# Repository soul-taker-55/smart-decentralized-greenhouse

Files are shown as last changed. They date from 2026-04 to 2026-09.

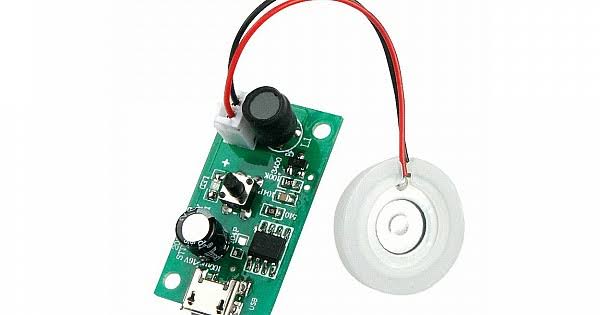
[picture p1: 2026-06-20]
Hardware Components/16) Ultrasonic Humidifier.jpg

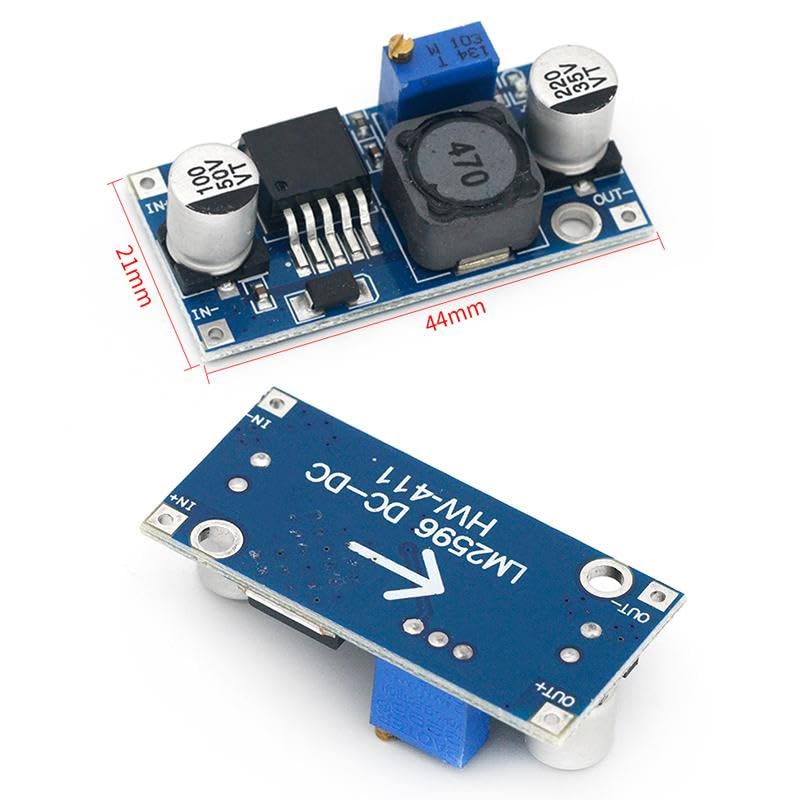
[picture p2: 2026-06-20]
Hardware Components/20) LM2596 HW-411 A.jpg

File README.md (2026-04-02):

# Smart Decentralized Greenhouse

A Secure and Decentralized IoT-Based Greenhouse Framework (SDIGF)

## Overview
This project presents an autonomous greenhouse system leveraging IoT devices, edge computing, and Zero Trust security principles.

## Key Concepts
- IoT
- Edge Computing
- Autonomous Control
- Zero Trust Architecture

## System Architecture

The system is designed as a decentralized IoT architecture consisting of:

- Device Layer (ESP32 sensors & actuators)
- Edge Layer (local decision-making)
- Communication Layer (MQTT over secure channels)
- Control Layer (automation logic)
- Monitoring Layer (dashboard & analytics)

## Team
- Ahmad Shaaban
- Dalaa Hag Mohammed
- Elias Zikra
- Maram Faisal Mohammed
- Mauricio Sayegh
- Omar Sawas

## Status
🚧 Under Development

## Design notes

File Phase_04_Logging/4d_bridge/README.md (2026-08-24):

# SDIGF Bridge — Phase 04d

Subscribes to the edge→server MQTT topics and writes what arrives into TimescaleDB.

Consumes the frozen contract at `Phase_04_Logging/4b_contracts/mqtt_contract_v3.md`.
Writes into the schema at `Phase_04_Logging/db/sdigf-db-schema-v2.sql`.

---

## What it is, and what it deliberately is not

The bridge is a **read-only observer of the edge**. It subscribes; it writes to Postgres;
it publishes nothing. It does not subscribe to `down/config` or `down/cmd`, and the
`sdigf-bridge` broker credential should not be granted publish rights on them.

Command publication belongs to the Phase 05a service layer. Keeping that line clean is
what makes it possible to say the logging tier has no path to an actuator — not as a
policy that could be relaxed, but as an absence of code.

The bridge is also **not in the control path**. If this process dies, the greenhouse keeps
running: the edge tier is autonomous by design and the only thing lost is the record. That
is the whole point of the tier split, and it is worth stating in the thesis in exactly
those terms.

---

## Topics

| Topic | QoS | Destination |
|---|---|---|
| `sdigf/v1/gh1/up/telemetry` | 0 | `telemetry` — 11 rows per message |
| `sdigf/v1/gh1/up/actuators` | 1 | `actuator_state` — 8 rows per message |
| `sdigf/v1/gh1/up/health` | 0 | `edge_events` — `HEALTH`, plus `REBOOT` when inferred |
| `sdigf/v1/gh1/up/ack` | 1 | `edge_events` — `ACK`, plus `CONFIG_APPLIED` when accepted |
| `sdigf/v1/gh1/status` | 1 | `edge_events` — `ONLINE` / `OFFLINE` |

Note that `status` sits at the root of the greenhouse tree, not under `up/`.

---

## Design decisions

### Time

`time` is **always the bridge's receipt time**. The device's own clock is preserved in
`device_ts`, and `ts_quality` records whether that clock was NTP-synced or boot-relative —
but neither drives the time axis.

The alternative, using the device clock when it is trustworthy and receipt time otherwise,
is more faithful to when a reading was taken. It was rejected because it produces a time
column whose meaning changes depending on a flag in another column. Any aggregate spanning
a reboot would silently mix two different notions of "when", and nothing in the query would
reveal it. One axis, one meaning, with the raw device value retained for anyone who wants
to reconstruct the other view.

All rows produced by a single message share one receipt timestamp, taken once.

### Deduplication

The contract requires uniqueness on `(greenhouse_id, seq, sensor_name)`. The schema's
unique index is on `(time, greenhouse_id, sensor_name, seq)` — TimescaleDB requires the
partitioning column in any unique index, so `time` cannot be left out.

**Those two are not the same guarantee.** Because `time` is receipt time, a QoS 1
redelivery arrives at a different instant and produces a different index key. The database
constraint would not catch it.

So the bridge checks explicitly before writing: has this `(greenhouse_id, seq)` already
been recorded within `DEDUP_WINDOW_MIN` minutes? QoS 1 redelivery happens within seconds of
a reconnect, so a 60-minute window is generous by orders of magnitude. The check is
DB-backed rather than in-memory, so it survives a bridge restart — which matters, because a
crash mid-processing is exactly when redelivery happens.

`ON CONFLICT DO NOTHING` remains on the insert as a second line of defence for the
exact-collision case.

> If this check ever shows up as slow, add:
> `CREATE INDEX ON telemetry (greenhouse_id, seq, time DESC);`
> At 30-second telemetry it is not close to mattering.

### Buffering and the bounded queue

MQTT delivery and database availability fail independently. Writes go into an in-memory
queue that drains in order, retrying with exponential backoff (1s → 30s cap).

The queue is **bounded** at `MAX_QUEUE_DEPTH`. When it fills, the oldest entry is discarded
and a counter increments. This is a deliberate trade: telemetry is QoS 0 and already
best-effort, so losing the oldest rows during a long outage is survivable, whereas an
unbounded queue turns a database outage into an OOM kill that loses everything *including*
the ability to recover. Drops are counted and logged rather than hidden.

Draining is strictly sequential. An `ONLINE` event followed by telemetry should land in
that order, and parallel writes would not guarantee it. Throughput is irrelevant at one
message per thirty seconds.

Constraint violations (Postgres error classes 22 and 23) are dropped rather than retried —
retrying a malformed row forever would wedge the queue behind one bad message.

### Persistent MQTT session

`clean: false` with a stable client ID. QoS 1 traffic — actuator state, acks, status — is
queued by the broker while the bridge restarts and delivered on reconnect. Telemetry is
QoS 0 and is not queued, which is the correct asymmetry: a gap in a 30-second sensor series
is recoverable from context, a missing `CONFIG_APPLIED` event is not.

### Validation before the write

The schema enforces the null rule with a CHECK constraint, so an invalid payload would be
rejected regardless. But it would be rejected as an opaque constraint violation at write
time, long after the context that would explain it is gone. Validating in the handler means
the log line names the sensor and the reason:

```
[error] [telemetry] rejected message: temp_in: q='fail' must carry val=null, got 0
```

A **missing** sensor is not treated as fatal — it is recorded as `init`, which is precisely
what "never successfully read" means, and the other ten readings are still evidence. An
**unrecognised** sensor is logged and ignored, so a firmware version that adds a sensor does
not stop the bridge writing the ones it understands.

### Reboot detection

The ESP32 cannot announce a reboot it has not yet booted from. The only available signal is
uptime going backwards between two health messages. When that happens the bridge writes a
distinct `REBOOT` row.

This matters because `boot_reason = brownout` is the documented signature of a stalled
canopy servo or an ESP32-CAM inrush on the shared 5 V rail, and `cfg_src = nvs` on the same
row is direct evidence of edge autonomy — the device restarted with no broker and resumed
from last-known-good config. Both would otherwise be buried inside a routine `HEALTH` row
among hundreds.

### Known omissions

`canopy.target` and `canopy.moving` are **not stored** — the schema has no column for them.
Both are transient: `moving` is true for under a second per adjustment, and `target` equals
`pos` except during that window. Neither answers a Phase 04 conflict question. Recorded here
so the omission is a decision on the record rather than something to rediscover later.

`vent` is stamped onto every row of a message rather than stored once. This is
denormalisation, and it is intentional: `vent` is derivable from the fan states, but the
contract publishes it because it is the value the control policy actually acted on. A
conflict query asking *what stage were we at when the humidifier was suppressed* should not
have to re-derive the policy's reasoning from its own outputs.

---

## Deployment

Separate Dokploy stack, same pattern as `sdigf-mock`.

Environment variables — set in Dokploy's environment tab, never committed:

```
MQTT_HOST=<broker host on dokploy-network>
MQTT_PORT=1883
MQTT_USER=sdigf-bridge
MQTT_PASS=<secret>

PG_HOST=<db service name on dokploy-network>
PG_PORT=5432
PG_USER=postgres
PG_PASS=<secret>
PG_DB=sdigf_db

GH_ID=gh1
LOG_LEVEL=info
MAX_QUEUE_DEPTH=5000
DEDUP_WINDOW_MIN=60
```

Use the **`sdigf-bridge`** credential, not `sdigf-edge` or `sdigf-admin`.

The bridge verifies the database is reachable and the schema is present *before* connecting
to the broker. Connecting to MQTT first would mean buffering messages it may have no ability
to store, and a wrong password would surface minutes later as a queue-depth warning rather
than immediately as what it is.

---

## Verifying it works

```sql
-- Is anything arriving?
SELECT count(*), max(time) FROM telemetry;

-- All eleven sensors, most recent message
SELECT sensor_name, value, unit, quality_flag
FROM telemetry
WHERE seq = (SELECT max(seq) FROM telemetry)
ORDER BY sensor_name;

-- Any duplicates? Should return zero rows.
SELECT greenhouse_id, seq, sensor_name, count(*)
FROM telemetry
GROUP BY 1,2,3 HAVING count(*) > 1;

-- Sensor health over the last day
SELECT sensor_name, quality_flag, count(*)
FROM telemetry
WHERE time > now() - interval '1 day'
GROUP BY 1,2 ORDER BY 1,2;

-- Connection and config history
SELECT time, event_type, boot_reason, cfg_src, cfg_ver
FROM edge_events
WHERE event_type IN ('ONLINE','OFFLINE','REBOOT','CONFIG_APPLIED')
ORDER BY time DESC LIMIT 20;
```

The bridge also logs a status line every five minutes:

```
[info] [bridge] status {"written":412,"duplicatesSkipped":3,"rejected":0,"dropped":0,"queueDepth":0}
```

---

## Testing performed

Verified against a live Mosquitto broker and a Postgres instance loaded with the real
schema, driven by the actual `4c_tool/mock-edge` simulator:

- 24 parser unit tests covering contract edge cases — null rule both directions, sentinel
  rejection, invalid quality flags, missing and unexpected sensors, out-of-range `vent` and
  `canopy.pos`, non-boolean `on`, invalid `src`, `ovr_s` present only when manual
- End-to-end: mock → broker → bridge → Postgres, 11 rows per telemetry message, 8 per
  actuator message, correct units and quality flags
- Retained `status` and `actuators` messages consumed on subscribe
- Duplicate suppression confirmed on a republished retained actuator message
- `ACK` accepted → `ACK` + `CONFIG_APPLIED` rows; rejected → `ACK` row and a warning
- Reboot inference from decreasing uptime, with `boot_reason=brownout` and `cfg_src=nvs`
  landing correctly
- Malformed JSON discarded without crashing
- Database stopped mid-run: 5 messages buffered, backoff 1s→2s→4s, all 55 rows recovered on
  restart, zero dropped

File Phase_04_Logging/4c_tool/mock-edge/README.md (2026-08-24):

# SDIGF Mock Edge Node

A stand-in for the ESP32. Publishes on the frozen MQTT contract
(`Contracts/mqtt_contract_v1.md`) so the entire server tier can be built,
tested, and demonstrated before firmware exists.

This is **not throwaway code**. It becomes the permanent test harness, the
regression suite, and the rehearsal target for the committee demonstration.
The control loop written here (Stage 2) is the reference implementation later
ported to firmware.

---

## Build stages

| Stage | Scope | Status |
|---|---|---|
| **1** | Connect, last will, telemetry, health, static actuator state | ✅ this release |
| 2 | Physics + control loop — actuators respond causally | planned |
| 3 | Config handling, safety envelope, acks | planned |
| 4 | Failure simulation, time acceleration, forced conditions | planned |

### What Stage 1 does

- Connects to EMQX with credentials and a **last will** on `status`
- Publishes `up/telemetry` every 10 s with all 11 readings, each carrying a
  quality flag, matching the contract exactly
- Publishes `up/health` every 60 s
- Publishes `up/actuators` once at connect (everything off — Stage 2 makes it real)
- Publishes retained `online` / `offline` on `status`
- Simulates ambient drift with bounded mean-reverting random walks, so charts
  and downsampling behave as they will in production

### What Stage 1 does *not* do

No physics linking actuators to conditions. No control loop. It does not
subscribe to `down/config` or `down/cmd`, and never sends an `up/ack`.
Soil moisture falls slowly and never recovers, because there is no pump yet.

---

## Deployment

Deployed as its **own Dokploy compose stack**, separate from `sdigf-server`, so
it can be stopped and started without touching the broker or database.

### 1. Create the stack

Dokploy → project `sdigf` → **Docker Compose** → Create

| Field | Value |
|---|---|
| Name | `sdigf-mock` |
| Provider | GitHub |
| Repository | `smart-decentralized-greenhouse` |
| Branch | `main` |
| Compose Path | `Tools/mock-edge/docker-compose.yml` |
| Watch Paths | `Tools/mock-edge/**` |

### 2. Environment variables

| Name | Value |
|---|---|
| `MQTT_HOST` | `sdigf-emqx` — the container name on `dokploy-network`, not the public domain |
| `MQTT_PORT` | `1883` |
| `MQTT_USER` | `sdigf-edge` |
| `MQTT_PASS` | the password set for `sdigf-edge` in EMQX |

Using the internal container name keeps mock traffic off the public interface
entirely. If the container name differs, take it from `docker ps`.

### 3. Deploy

Dokploy builds the image and starts the container. Logs should show:

```
[mqtt] connected to sdigf-emqx:1883 as sdigf-mock-edge
[mock] publishing telemetry every 10s, health every 60s
```

---

## Verification

**In MQTTX**, connect as `sdigf-admin` and subscribe to `sdigf/v1/gh1/#`.

| Check | Expected |
|---|---|
| Telemetry arrives | a message every 10 s on `up/telemetry` |
| Values drift | consecutive readings differ slightly, not identical |
| `seq` increments | 1, 2, 3 … with no gaps |
| Health arrives | every 60 s on `up/health`, retained |
| Status is online | `up/status` shows `{"state":"online"}` with the **Retained** badge |

**In the EMQX dashboard**, Clients should list `sdigf-mock-edge` as connected,
and Messages In Rate should be non-zero.

**Last-will test.** Stop the stack in Dokploy — that is a graceful stop, so the
mock publishes `offline` itself. To test the *will* specifically (ungraceful
disconnect), kill the container:

```bash
docker kill <mock-container-name>
```

The broker then publishes the retained `offline` message on its behalf. Stage 4
adds a cleaner way to trigger this for demo purposes.

---

## Configuration

All via environment variables; nothing is hardcoded.

| Variable | Default | Meaning |
|---|---|---|
| `MQTT_HOST` | *required* | Broker hostname |
| `MQTT_PORT` | `1883` | Broker port |
| `MQTT_USER` | *required* | Broker username |
| `MQTT_PASS` | *required* | Broker password |
| `MQTT_CLIENT_ID` | `sdigf-mock-edge` | Fixed, matching the real ESP32 pattern |
| `GH_ID` | `gh1` | Greenhouse slot in the topic tree |
| `FW_VERSION` | `mock-0.1.0` | Reported in `up/health` |
| `TELEMETRY_INTERVAL_S` | `10` | Telemetry publish interval |
| `HEALTH_INTERVAL_S` | `60` | Health publish interval |

---

## Swapping to the real ESP32

The intended endpoint is that swapping in real hardware is a **connection
change and nothing else**. Same topics, same payloads, same client ID pattern.
Stop this stack, power on the ESP32, and the server tier should not notice.

Note the one honest difference: this mock reports `tsq: "ntp"` because it runs
on a server with a real clock. The ESP32 reports `tsq: "boot"` until NTP syncs,
and the bridge must handle that case — see contract §2.

---

## Files

```
Tools/mock-edge/
├── docker-compose.yml     Dokploy stack definition
├── Dockerfile             node:20-alpine, runs as non-root
├── package.json
├── README.md
└── src/
    ├── config.js          Environment config and topic construction
    ├── environment.js     Simulated conditions (Stage 2 adds actuator physics)
    └── index.js           MQTT connection and publish loops
```

Topics are constructed in exactly one place (`config.js`) so a typo cannot
diverge between publishers.

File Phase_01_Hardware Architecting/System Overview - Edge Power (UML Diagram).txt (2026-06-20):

@startuml
skinparam rectangleBorderColor #555
rectangle "220-230 V AC mains" as mains
rectangle "S-25-5 PSU" as psu
rectangle "5 V rail" as r5 #ffe8e0
rectangle "LM2596 buck" as buck
rectangle "3.3 V rail" as r33 #e0ecff
rectangle "Grow light 220 V\n(relay CH7, mains-isolated)" as grow
rectangle "ESP32 5V pin\nrelay coils (JD-VCC)\nLCD, MQ135 heater\nMG996R servo (V+)\nDC loads via relay contacts" as loads5 #ffe8e0
rectangle "BMP280 x2, DHT11 x2\nLDR x2, soil, water\nencoder, relay logic (VCC)\nlevel-converter LV" as loads33 #e0ecff

mains --> psu
psu --> r5
r5 --> buck
buck --> r33
mains --> grow
r5 --> loads5
r33 --> loads33
@enduml

@startuml
left to right direction
skinparam rectangleBorderColor #555
rectangle "220-230 V AC mains" as mains
rectangle "S-25-5 PSU" as psu
rectangle "5 V rail" as r5 #ffe8e0
rectangle "LM2596 buck" as buck
rectangle "3.3 V rail" as r33 #e0ecff
rectangle "Grow light 220 V\n(relay CH7, mains-isolated)" as grow
rectangle "ESP32 5V pin\nrelay coils (JD-VCC)\nLCD, MQ135 heater\nMG996R servo (V+)\nDC loads via relay contacts" as loads5 #ffe8e0
rectangle "BMP280 x2, DHT11 x2\nLDR x2, soil, water\nencoder, relay logic (VCC)\nlevel-converter LV" as loads33 #e0ecff

mains --> psu
psu --> r5
r5 --> buck
buck --> r33
mains --> grow
r5 --> loads5
r33 --> loads33
@enduml

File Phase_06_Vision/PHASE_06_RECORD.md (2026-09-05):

# PHASE 06 RECORD — Vision Node (ESP32-CAM)

**Status:** device firmware live, server tier deployed to `greenhouse.progrex.tech`,
scheduled upload path verified end to end on real hardware. One path — the
manual snapshot request — is **built but not yet confirmed working**.
**Commits:** `e10f429` … `3a696ea` (20 commits, 3–4 September 2026). Base: `77988d4`.
**Hardware:** AI-Thinker ESP32-CAM, MAC `B4:BF:E9:34:4C:18`, 4 MB flash, PSRAM present.

This record states what was decided, what was found, what was wrong, and what
was observed — in that order.

---

## 1. What Phase 06 contributes — stated narrowly

A camera that photographs the enclosure on a schedule, uploads over HTTPS, and
presents its history in the dashboard.

It contributes **nothing to control**. The vision node cannot move an actuator,
cannot approve a config, and holds no role in the RBAC matrix. If it fails
entirely, the greenhouse is unaffected. That isolation is the point, and it is
enforced structurally rather than by convention: `camera_images` has no
relationship to `config_profiles` or `commands`, and the device's credential
(`device-auth.js`) is checked by a module that imports nothing from `auth.js`
and exports nothing to it.

What it does not yet contribute: any analysis. Green coverage, leaf area and
growth measurement are **not built**. This phase produces the dataset those
would need; it does not consume it.

---

## 2. The hardware is not what it was sold as

**The board is labelled ESP32-CAM with an OV2640. The sensor is not an OV2640.**

Sensor PID reads `0x2145` — OV7670-class. The distinguishing property, and the
one that mattered: **it has no hardware JPEG encoder.**

This was discovered the hard way. `esp_camera_init()` failed with `0x106` and
the driver's own message was misleading:

```
E (1958) camera: JPEG format is not supported on this sensor
[CAM] init FAILED 0x106
```

Read carelessly, "not supported on this sensor" suggests a misidentified or
faulty sensor. It means exactly what it says: the sensor was identified
correctly and cannot produce JPEG. The fix was a format change
(`PIXFORMAT_JPEG` → `PIXFORMAT_RGB565`), not a hardware change.

The diagnostic that settled it was a controlled comparison, not reasoning:

| camera connected | camera physically removed |
|---|---|
| `JPEG format is not supported on this sensor` | `Detected camera not supported` |

Two different messages means the driver was reading the sensor successfully in
one case and not at all in the other. That distinction is what ruled out a
connection fault.

### The consequence, measured

Raw RGB565 at QVGA is 153,600 bytes per frame — too large to upload at any
useful interval. Software encoding via `frame2jpg()` was chosen over buying a
genuine OV2640, because a replacement part was not available.

Measured on the device:

```
[JPG] #1  raw 153600 B -> jpg 7160 B  (21.5x)  104 ms  heap 173216
[JPG] #2  raw 153600 B -> jpg 7338 B  (20.9x)  103 ms  heap 172952
[JPG] #3  raw 153600 B -> jpg 7299 B  (21.0x)  101 ms  heap 172952
[JPG] #4  raw 153600 B -> jpg 7250 B  (21.2x)  100 ms  heap 172952
```

**~7 KB per frame, ~100 ms encode, heap flat across frames.** At one frame per
day that is roughly 2.5 MB a year.

This is worth stating plainly for the thesis: the workaround is not a
compromise in outcome. The bandwidth objection to a JPEG-less sensor
disappeared once the numbers were measured. It cost ~100 ms of CPU on a device
with no latency requirement. **The case for replacing the sensor is weaker
after measurement than it was before it** — which is the opposite of what was
assumed when the mismatch was found.

---

## 3. Two hardware faults that were not code faults

Both cost significant time and both were diagnosed wrongly at first. Recording
them because the wrong diagnoses are as instructive as the right ones.

### 3.1 The flash failure was a 5 V/3.3 V miswiring

Symptom: `esptool` connected, identified the chip, wrote the bootloader, then
failed verification with the **same MD5 every time**:

```
Input MD5: 42863d8b59e70f04bf1f3b0d5aae512e
Flash MD5: 7122cb1ef38a66d8813a9f9913af4682
```

Four theories were proposed and all four were wrong: serial noise, baud rate,
flash write-protection, and a counterfeit flash die. Each was ruled out by
evidence — the status register read `0x0000` (no protection), the failure
persisted at 115200 as well as 460800 (not baud), and the identical MD5 across
attempts ruled out random noise.

The actual cause: **the module was wired to 3.3 V instead of 5 V.** Enough to
boot, enough to talk over UART, not enough for the flash die to complete
writes.

The diagnostic signal that should have been weighted higher, and was noticed
but dropped:

```
Erasing flash memory (this may take a while)...
Flash memory erased successfully in 0.0 seconds.
```

A real erase of 4 MB does not complete in 0.0 seconds. That line was visible
from the first failed attempt.

### 3.2 The brownout was FTDI-supplied power

After flashing worked, the first upload succeeded and the second reset the
board:

```
[UP ] OK  status 201  1841 ms  (ok=1 fail=0)
[JPG] #2  7798 B  heap 157472
E BOD: Brownout detector was triggered
```

The upload path draws more current than anything tested before it: capture,
software JPEG encode, TLS handshake and WiFi transmit all inside a few hundred
milliseconds. The FTDI adapter's 5 V pin could not supply the spike.

Moving the CAM's 5 V and GND to the S-25-5 PSU rail resolved it. Uploads have
run without a brownout since.

**This is not a design flaw discovered — it is the documented power constraint
in the Phase 01 wiring doc arriving on schedule.** The CAM's own solid 5 V feed
was specified before any of this was built. The bench setup violated it.

---

## 4. Design decisions

### 4.1 Polling, not push — forced by the network, not chosen

The server cannot open a connection to the camera. The device sits on its own
WiFi network behind NAT with no inbound port. Every exchange is therefore the
camera asking the server.

This is the same shape as the retained-config pattern in Phase 04/05a — state
the device discovers rather than state delivered to it — arrived at
independently, for the same underlying reason.

It has a visible consequence the UI must not hide: **pressing "Request
snapshot" cannot produce an image immediately.** The dashboard says
"Requested — waiting for the camera to poll" rather than showing a spinner that
would imply a request is in flight to a device nothing can contact.

### 4.2 HTTP POST, not MQTT or RTSP

MQTT would mean a 7 KB binary payload through a broker whose contract (v4) has
no topic for it, plus a new account and ACL entry, for a node that is
deliberately outside the control contract. RTSP would mean a continuous stream
from a brownout-sensitive device for a timelapse use case that needs one frame
a day.

### 4.3 Device auth is separate from user auth, deliberately

`device-auth.js` checks a single static bearer token on two routes only:
`POST /api/camera/upload` and `GET /api/camera/pending`. It grants access to
nothing else.

Keeping it out of `auth.js` is not tidiness. The camera is not a user and holds
no role; folding its credential into the module that implements the ADMIN /
ENGINEER / FARMER matrix would create a path for device-shaped and user-shaped
authority to blur over time. The two dashboard-facing camera routes
(`/latest`, `/days`, `/pending-status`) sit behind `CAP.VIEW` — the same
capability that gates sensor readings, because an image is an observation
available to every role, not an actuation.

`GET /api/camera/pending` and `GET /api/camera/pending-status` return the same
data through two routes for exactly this reason: one authenticates a device by
token, the other a human by session. Sharing one route would require either
handing the dashboard a device token or letting a device token satisfy a
user-facing route.

### 4.4 Metadata is copied at upload, not joined at display

`camera_images.canopy_position` and `.photoperiod_active` are read from
`actuator_state` at the moment of upload and stored on the row.

Joining live would mean a later canopy movement retroactively changes what an
already-captured photograph is understood to show. This mirrors the
retrospective e-stop record pattern from Phase 05b: a record of what was true
when the event happened, immune to what happens after.

**Honest limit:** as of this phase those values come from the Phase 04 mock
edge simulator, which publishes static actuator states. The columns are
populated correctly and mean nothing yet. They become meaningful when Phase 02
firmware runs, with no schema or code change required. A reader must not
mistake "populated" for "true".

### 4.5 Stills, not video

Video was considered and rejected. Without a hardware encoder each frame costs
~100 ms to compress, capping the achievable rate around 8–10 fps before network
overhead; and streaming would require holding a connection open, which the NAT
constraint above rules out.

More decisively: plants change over days. One frame per day at known conditions
is more useful for growth tracking than video, and produces a dataset that can
be analysed rather than a stream that must be watched.

---

## 5. Verified live, on the deployed stack

- Migration `010_camera.sql` applied to `sdigf_backend`; both tables present,
  `camera_pending` seeded with one row.
- `POST /api/camera/upload` **without** a token → `401 device_unauthorized`.
- `POST /api/camera/upload` **with** the token → `201`, row inserted.
- File confirmed on the Docker volume with correct ownership:
  ```
  -rw-r--r-- 1 node node 22 Sep 3 22:10 /data/camera-images/2026/09/1788473442950.jpg
  ```
- Row and file agree on size; `canopy_position` and `photoperiod_active`
  populated from telemetry (`0`, `f`).
- **Real device upload from the ESP32-CAM: `201`, image visible in the
  dashboard.** Full path proven — capture, software encode, HTTPS with device
  token, volume write, database row, rendered page.
- NTP sync working; `x-captured-at` carries a real device timestamp.
- Day-grouped history renders correctly: 9 images across 2 days, Today /
  Yesterday grouping, thumbnail strip, selection.

### A deployment bug found by the first real upload

The first authenticated upload failed:

```
EACCES: permission denied, mkdir '/data/camera-images/2026'
```

The Dockerfile ends with `USER node`, and Docker seeds a new named volume's
ownership from whatever exists at the mount point — which was nothing, so the
volume arrived owned by root. Fixed by creating and chowning the directory in
the image before dropping privileges (`dcdd2d7`).

Note the fix required **deleting the existing volume**, not just redeploying:
Docker only sets ownership when initialising an empty volume.

---

## 6. Open items

### 6.1 The manual snapshot path is unconfirmed

`POST /api/camera/request-snapshot` sets the flag. The firmware polls
`GET /api/camera/pending` every 10 s and should capture with
`x-trigger: manual` on a positive result, which the server clears on receipt.

**Server side is tested. The device-side poll has not been observed working.**
At the time of writing the dashboard shows the flag set and every uploaded
frame marked `schedule`. Either the device is running an older sketch or the
poll is failing — both produce the same visible symptom and neither has been
distinguished, because serial output is currently unreadable (see 6.2).

Do not describe this path as working until a frame with `trigger = 'manual'`
appears in `camera_images`.

### 6.2 Serial monitoring is not connected

Once the CAM was moved to PSU power, the FTDI's ground was left disconnected,
so the serial line has no shared voltage reference and returns garbage. One
wire fixes it — FTDI GND to CAM GND, with the PSU ground also connected.

Consequence while it stays broken: a brownout-and-recover cycle is
indistinguishable from a merely late image, and `[PLL]` diagnostics for 6.1 are
invisible.

### 6.3 TLS certificate validation is off

`WiFiClientSecure::setInsecure()`. The endpoint accepts image uploads gated by
a bearer token; an attacker positioned to intercept could see or drop a JPEG,
not reach any control-path route. Certificate pinning against
`greenhouse.progrex.tech` is future work. Stated in the sketch header rather
than silently skipped.

### 6.4 The device token has been exposed in a chat transcript

It must be rotated: regenerate with `openssl rand -hex 32`, update in Dokploy
and in `secrets.h` together, redeploy.

### 6.5 No retention policy

At one frame a day this is not urgent — a year is a few hundred files and a
few megabytes. It becomes a question if the interval is ever shortened.

### 6.6 No analysis

Green coverage, leaf area, canopy coverage: not built. This phase produces the
dataset; consuming it is separate work and should not be claimed as part of
Phase 06.

---

## 7. Methodology notes

**The board's label was wrong and the driver's error message was misleading.**
The sensor identity was settled by a controlled comparison (camera connected vs
removed), not by trusting either.

**Three diagnostic tools proposed in this phase were themselves wrong**, and
each was withdrawn once its evidence failed to distinguish anything: an SCCB
bus probe that ran after `esp_camera_init` had already powered the sensor down
and therefore reported "no response" in every case; a baud-rate theory
contradicted by the failure persisting at 115200; a write-protection theory
contradicted by a status register reading `0x0000`. A diagnostic that returns
the same answer whether or not the fault is present measures nothing.

**A schema assumption was caught by reading the schema.** The first draft of
`camera-service.js` queried `actuator_state` for a JSONB `state` column on the
backend connection pool. The real table lives in `sdigf_db` (requiring the
read-only `queryTelemetry` pool), stores one row per actuator, and uses
`greenhouse_id`/`time` rather than `gh_id`/`recorded_at`. Every one of those
would have failed at runtime. Corrected before delivery by reading
`sdigf-db-schema-v2.sql` rather than reasoning from the code.

**Two frontend helpers were invented rather than looked up** — `fmtWhen()` for
a function actually named `when()`, and a CSS class `err` that does not exist
where the codebase uses `fielderr`. Both would have failed at build time. Both
were caught by grepping the files before delivery.

**`git add .` was run once during this phase.** It staged nothing dangerous —
`secrets.h` was already protected by a `.gitignore` written before the file
existed, and `git check-ignore -v` confirmed the rule matched on the bare
filename. The staging was reset. The protection held precisely because the
ignore rule preceded the secret.

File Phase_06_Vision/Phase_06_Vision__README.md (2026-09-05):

# The Camera — A Plain-Language Guide

This explains what the camera does, how it was built, and — just as
importantly — what it deliberately cannot do.

If you read only one section, read the first.

---

## First, the most important thing

**The camera cannot control anything.**

It photographs the inside of the greenhouse. That is all it does. It cannot
turn on a fan, open the shade canopy, run the pump, or change a setting. If
someone replaced every photograph with a picture of a dying plant, nothing in
the greenhouse would move in response.

This is not an accident or a limitation to be fixed later. It is the design.

The reason is that the greenhouse's central promise is that the plants survive
without the server. The control system is deliberately simple, deterministic
and local: thresholds on the controller, running whether or not anything else
in the world is reachable. A camera is the opposite kind of component — it
depends on the network, its output needs interpretation, and interpretation can
be wrong. Letting it act would put an unreliable, network-dependent,
sometimes-wrong component into the path that keeps plants alive.

So the camera **observes and reports. A human decides.**

---

## What it actually is

A second, separate microcontroller — an ESP32-CAM — with its own WiFi
connection. It shares exactly one thing with the greenhouse's main controller:
the 5-volt power supply. No data connection, no shared pins, no shared network
account.

It takes one photograph per day, plus any extra ones a person requests, and
uploads them to the server. The dashboard shows them grouped by day.

---

## Question 1 — "What is the source code?"

### `Phase_06_Vision/6a_cam_firmware/cam_bringup/cam_bringup.ino` — the device

The camera's own program. It starts the camera, joins WiFi, syncs its clock,
then loops: take a photograph, compress it, send it.

### `5a_web/db/010_camera.sql` — where records are kept

Two tables. `camera_images` holds one row per photograph — when it was taken,
how big it is, where the file lives, and what the greenhouse's shade canopy and
grow light were doing at the time. `camera_pending` is a single row holding
whether someone has asked for an extra photograph.

The photographs themselves are **not** stored in the database. They live as
ordinary files on disk, and the database holds the path to each one. Putting
image data in the same table the dashboard queries constantly would make every
unrelated question slower.

### `5a_web/backend/src/services/camera-service.js` — receiving and filing

Writes the file, records the row, groups the history by day.

### `5a_web/backend/src/device-auth.js` — proving which camera

Twelve lines that check one thing: does this upload carry the right password?
Deliberately kept separate from the file that handles human logins, for a
reason explained below.

### `5a_web/backend/src/camera-routes.js` — the endpoints

Five addresses the camera and the dashboard talk to.

### `5a_web/frontend/src/components/ActivityPage.jsx` — the panel

The Camera page: the current photograph large, a list of days, and a strip of
thumbnails for the selected day.

---

## Question 2 — "How does it work?"

### Taking the picture

The camera chip on this board turned out not to be the one the board is
labelled with. The advertised sensor compresses images in hardware; the one
actually fitted does not.

The uncompressed photograph is about 150 kilobytes. Sending one of those every
day would be wasteful, and sending them more often would be worse. So the
compression is done in software instead — the microcontroller does the work the
missing hardware would have done.

It costs about a tenth of a second per photograph and shrinks each one to
roughly 7 kilobytes — about twenty times smaller. For something that takes one
picture a day, a tenth of a second is nothing.

This is worth being straight about: it is a workaround for hardware that was
not what it claimed to be. But after measuring it, the workaround costs almost
nothing, and replacing the sensor would not meaningfully improve the result.

### Sending it

The camera sends each photograph to the server over an encrypted connection,
along with a password that identifies it as the greenhouse's camera and not
some stranger's.

### Why the "Request snapshot" button does not take a picture immediately

This surprises people, so it is worth explaining properly.

**The server cannot contact the camera.** The camera sits on a home network,
behind a router, with no public address. Nothing on the internet can start a
conversation with it — the same reason your laptop is not reachable from the
open internet by default.

So the conversation only ever goes one way. The camera asks the server: "has
anyone requested a photograph?" It asks every ten seconds. When the answer is
yes, it takes one and uploads it.

The button does not send a command to the camera. It writes a note that the
camera will find next time it asks. That is why the page says *"Requested —
waiting for the camera to poll"* rather than showing a loading spinner. A
spinner would be a small lie: it would suggest something is on its way to the
camera, when in truth nothing can be.

### Why the camera has its own password, separate from human logins

People who use this system log in with a username and password and get a role —
administrator, engineer, or farmer — which decides what they can do.

The camera has none of that. It is not a person, it has no role, and it can do
exactly two things: upload a photograph, and ask whether one has been
requested. Its password proves *which camera*, and nothing more.

The code that checks the camera's password is kept in a completely separate
file from the code that checks human logins. If they shared a file, it would be
easy — over months of changes — for the camera to accidentally acquire
human-shaped permissions, or for a human route to accept a camera's password.
Separating them makes that mistake difficult rather than merely unlikely.

---

## Question 3 — "What is stored?"

For each photograph:

- the picture itself, as an ordinary JPEG file
- when it was taken, according to the camera's own clock
- when the server received it
- how large it is
- whether it was the daily scheduled photograph or one someone requested
- who requested it, if anyone
- what the shade canopy position and grow light state were at that moment

That last item exists so a photograph can be understood in context — a picture
taken with the shade closed looks different from one taken with it open, and
that difference should not be mistaken for the plants changing.

**One honest caveat.** Those canopy and light values currently come from a
simulator, not the real greenhouse hardware, because the main controller's
firmware has not been written yet. The values are recorded correctly and mean
nothing yet. They will start meaning something the moment the real controller
runs, with no changes needed here.

---

## What this proves, and what it does not

### It proves

- A photograph reaching the server was uploaded by something holding the
  camera's password.
- The photograph has not been altered since it was written to disk.
- The record of when the server received it is accurate.

### It does not prove

- **That the camera's own clock was right.** The camera reports when it took
  each picture, and the server has no way to check. If the camera's clock is
  wrong, the recorded capture time is wrong. This is the same limitation the
  audit ledger documents elsewhere in this project, in miniature.
- **That the photograph shows what it appears to show.** Nothing verifies that
  the camera is pointed at the greenhouse.
- **Anything about the plants.** No analysis is performed. There is no
  measurement of growth, leaf area or health. Those would be built on top of
  this; they do not exist yet.

---

## What is not finished

- **Requested snapshots are built but not yet confirmed working.** The button
  and the server side are tested. The camera's side of it has not been observed
  working end to end.
- **The connection is encrypted but the server's identity is not verified.**
  The camera accepts whatever certificate it is offered. Since the only thing
  at risk is a photograph, this was judged acceptable for now and recorded
  rather than hidden.
- **No analysis of the images.** As above.

---

## In one paragraph

A second small computer photographs the greenhouse once a day, compresses each
picture in software because the camera chip it shipped with cannot do it in
hardware, and uploads it to the server with a password that identifies it as
this greenhouse's camera. The server files the picture, records when it was
taken and what the shade and lighting were doing at the time, and the dashboard
presents the collection day by day. The camera can be asked for an extra
picture, but only by leaving a note it will find the next time it checks —
because nothing can reach it directly. And whatever it sees, it cannot act on:
the camera observes, and a person decides.

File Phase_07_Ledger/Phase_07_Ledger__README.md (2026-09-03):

# The Audit Chain — A Plain-Language Guide

**For a reader who is not a programmer.**

This folder documents Phase 07 of the Smart Decentralised Greenhouse. It answers
three questions an examiner has asked, in ordinary language, and points at the
exact files where each answer can be checked.

> **Where the code actually lives.** This folder holds documentation. The code
> itself is part of the web server and lives under
> `Phase_05_Backend_Dashboard/5a_web/`, because the audit chain is a feature of
> the running application rather than a separate program. Splitting it into its
> own folder would have divided one working system across two places.

---

## First, the most important thing

**This is not a blockchain, and the project does not claim it is.**

The correct name is a **hash-chained log**. The difference matters, and stating
it plainly is part of the work rather than an admission against it.

A blockchain has many independent computers that do not trust each other, all
keeping their own copy of the same record and voting on what is true. That
arrangement solves a specific problem: *how do strangers agree on a shared
history when no one is in charge?*

This greenhouse has one server, one database, and one administrator. There are no
strangers and no disagreement to settle. Building a blockchain here would add the
machinery of distributed agreement without the problem it solves — and every
claim that machinery normally supports would be false, because one person still
controls every copy.

So the project uses the one piece of the idea that genuinely applies: **linking
records together mathematically so that changing an old one is detectable.**
That is the hash chain. The rest is left out, honestly and on purpose.

---

## Question 1 — "What is the source code?"

Four files. Each does one thing.

### `5a_web/db/006_ledger.sql` — the table

Creates the storage. One row per recorded action, each holding: its position in
the chain, which action it describes, the fingerprint of the row before it, its
own fingerprint, and the exact text that fingerprint was calculated from.

Deliberately, this table has **no automatic protections** against deleting rows.
That looks like a mistake and is not. If the database physically prevented
someone from deleting a record, the check that detects deleted records could
never fire — the database would be quietly stopping the very thing the system is
trying to catch and prove. The record has to be *deletable* for the deletion to
be *detectable*.

### `5a_web/backend/src/ledger-link.js` — building one link

Takes one recorded action, writes it out as text in a completely fixed way, and
calculates its fingerprint.

"Completely fixed" is the whole job. If the same action could be written out two
slightly different ways — a space here, a date formatted differently there — the
two versions would produce different fingerprints, and honest records would look
tampered with. This file exists so that there is exactly one way to write
anything down, forever.

It handles no databases and no network. That makes it possible to test on any
computer, with nothing installed.

### `5a_web/backend/src/services/ledger-service.js` — writing and checking

Two jobs.

**Writing:** when the system records an action, this adds it to the chain in the
same breath, so an action cannot be recorded without being chained.

**Checking:** re-reads the whole chain and asks five questions. Does each link
point correctly at the one before it? Does each fingerprint still match its own
stored text? Does that text still match the live records it describes? Does the
action it refers to still exist? And is there any recorded action with no link at
all?

The fifth question is there because of the tidy attacker — someone who deletes
both the record and its link, leaving nothing dangling. The first four questions
only look at the chain, so they would see nothing missing. The fifth looks at the
records.

### `5a_web/backend/tools/tamper-demo.mjs` — the proof

A program that attacks the chain on purpose, six different ways, and prints what
the checking found. See "Running the demonstration" below.

---

## Question 2 — "How did you perform it?"

Every time the system records something an authorised person did — approving a
configuration, issuing a command, registering a signing key — it also writes a
**fingerprint** of that record.

A fingerprint here is a short string of letters and numbers produced from the
record's exact contents. Change one character anywhere in the record and the
fingerprint comes out completely different. It cannot be worked backwards, and
you cannot craft a different record that produces the same fingerprint.

The chain comes from one extra step: **each record's fingerprint is calculated
with the previous record's fingerprint included in it.**

```
   Record 1  ──▶ fingerprint A
   Record 2 + A ──▶ fingerprint B
   Record 3 + B ──▶ fingerprint C
```

Now suppose someone edits Record 2. Its fingerprint is no longer B. But Record 3
still expects B. The mismatch is visible, and so is every link after it. To hide
one edit you must rebuild everything that follows it.

**One thing goes further.** When an engineer approves a configuration, they sign
it with a private key that exists only in their own browser — the server never
receives it and has no place to store it. That signature is pulled into the
fingerprint calculation too. So the chain covers not only *what happened* but
*who cryptographically agreed to it*, and editing an approval in a different
table still breaks the chain.

You can see this yourself. Log into the dashboard and open **Activity**. The
panel at the top runs the full check when the page loads, and reports the result
in words — never a green tick, for reasons the panel itself explains.

---

## Question 3 — "Do you store any data on it?"

**No. Only evidence about the data.** The distinction is the design.

| Kind of thing | Where it lives | In the chain? |
|---|---|---|
| Configuration values — temperatures, watering thresholds | `config_profiles` table | **No** |
| Sensor readings, temperature and humidity history | separate `sdigf_db` database | **No** |
| Who did what, and when | `server_events` table | **Fingerprint only** |
| An engineer's approval signature | `config_approvals` table | **Fingerprint only** |

The chain holds fingerprints and links. The actual values stay in ordinary
database tables where the application reads and writes them normally.

**This is what makes tampering detectable.** Because the fingerprint was
calculated *from* the configuration and *from* the signature, the two must always
agree. Someone editing the database directly changes the configuration — but they
cannot change the fingerprint to match without also rebuilding every link after
it. The check re-reads the live records, recalculates, and finds the mismatch.

Keeping the values out of the chain is also the practical choice. Sensor readings
arrive continuously; a chain over them would grow without limit and would prove
nothing useful, because — see the honest limits below — no chain can make a
sensor honest.

---

## What this proves, and what it does not

The system states both. The second list is the more valuable one.

### It proves

No individual record was altered, deleted, or reordered after it was written, and
no recorded action is missing its link. Any single change of that sort is
detected and reported, naming the record and the field that changed.

Separately and more strongly: **an approval that was never given cannot be
invented.** The signature can only be produced by the private key, the key never
leaves the engineer's browser, and the server has never held it. Not even the
administrator can forge one.

### It does not prove

**The history as a whole cannot be authenticated.** An administrator with full
database access can delete a stretch of records and rebuild every link after
them, and the check will report that everything is fine. This is demonstrated
deliberately as the sixth scenario of the tamper demonstration.

The reason is simple: the chain begins inside this system, so a chain rebuilt
from the beginning is internally consistent by construction. Fixing this means
publishing the latest fingerprint somewhere the administrator cannot reach — a
newspaper, a public registry, another organisation's system. That is named as
future work and has not been built.

**A related limit worth stating.** After such a rewrite, the system reports a
number describing how much of the chain was recorded as it happened. Because the
rewriter wrote those rows, they choose that number too. It is a disclosure for an
honest operator, never a defence against a dishonest one.

**And the deepest limit.** No chain of this kind can confirm that a sensor
reading was truthful, only that what was written down has not been altered since.
If a sensor lies, or a device misreports when something occurred, the record is
faithfully preserved — and faithfully wrong. This is known as the Oracle Problem.
Most published work combining farming sensors with blockchains does not mention
it. This project states it plainly, because a chain that appears to guarantee
truthfulness would be making a promise it cannot keep.

---

## Running the demonstration

The demonstration attacks the chain six ways and prints what the checking found.
It is safe: it builds its own temporary database, damages that, and deletes it
afterwards. **The database this demo creates and destroys is fixed in the code
and cannot be changed by configuration. It never touches the project's real
data.**

### What you need

A running PostgreSQL database and its password. That is all — everything else is
included in the repository.

### The command

From `Phase_05_Backend_Dashboard/5a_web/backend`:

```bash
PG_PASS=<the database password> node tools/tamper-demo.mjs
```

Windows PowerShell:

```powershell
$env:PG_PASS="<the database password>"; node tools/tamper-demo.mjs
```

If something is missing, the program says so in a sentence and stops — for
example *"CANNOT RUN — no PostgreSQL server is listening at 127.0.0.1:5432"*,
followed by the command that fixes it. It checks before it starts, so it never
begins a demonstration it cannot finish.

Takes a few seconds. Prints a section per scenario.

### What you will see

| # | The attack | What the check reports |
|---|---|---|
| 1 | Change who performed an action | Detected, naming the field and both values |
| 2 | Delete a recorded action | Detected — the link points at nothing |
| 3 | Change an engineer's approval signature | Detected, **in a different table** from the chain |
| 4 | Delete a link from the chain | Detected — the next link no longer fits |
| 5 | Delete a link *and* its record together | Detected — a record exists with no link |
| 6 | Delete records and rebuild the whole chain | **Not detected — and that is the point** |

Scenario 3 is the one to watch. The change is made in a completely separate
table, yet the chain still breaks — because the approval signature was pulled
into the fingerprint when the link was built.

Scenario 6 is the closing demonstration and the most valuable. The check reports
everything is fine after a successful attack. The program then does one more
thing: it takes the engineer's surviving signature and verifies it against their
registered key. It still checks out. The ordering and the story were destroyed;
the proof that a particular engineer approved a particular configuration was not.

The program is careful to say exactly how far that goes. This attack deleted the
activity records; it did not delete the approval itself. An administrator who
deleted the approval too would leave nothing to verify. **The claim is that a
past approval cannot be forged — never that it cannot be erased.** Those are
different properties, and the demonstration says so on screen rather than letting
the stronger reading stand.

---

## In one paragraph

Every action taken through this system is recorded, and each record is
mathematically linked to the one before it, so that altering an old record breaks
the links that follow and the break can be found and named. Approvals go further:
they are signed with a key the server never sees, so an approval that was never
given cannot be manufactured by anyone, including whoever runs the server. What
the system does not claim is equally important — a determined administrator can
still destroy history, and no system of this kind can make a sensor tell the
truth. The project states those limits openly, because a design that hid them
would be claiming more than it can deliver.

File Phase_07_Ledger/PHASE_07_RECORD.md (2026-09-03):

# PHASE 07 — THE LEDGER. PHASE RECORD.

Hand this to the planner. Repo is canonical; everything below was checked against
it or against the live system, not against chat history.

---

## 1 · WHAT PHASE 07 CONTRIBUTES — STATED NARROWLY

Phase 07 adds **nothing** to the trust model. It is not a second trust mechanism.

> **The chain-integrity check turns "erasable" into "detectably erasable."**

An administrator can still delete or rewrite session-attributed history. What they
cannot do is leave the chain consistent afterwards without rebuilding every
subsequent link. The record does not become unfalsifiable; it becomes falsifiable
only in ways that announce themselves.

Not a blockchain, not consensus, not distributed trust. One operator, one
database, one root credential.

**The Oracle Problem, stated rather than omitted:** no ledger can verify that a
sensor reading was honest, only that what was written has not been altered since.
Some chained events — retrospective local emergency stops — describe things the
server did not witness. The chain proves such a record was not altered after the
fact. It does **not** prove the originally reported time was true. That is a
different claim from the chain's usual one.

---

## 2 · WHAT WAS BUILT

| Path | Purpose |
|---|---|
| `5a_web/db/006_ledger.sql` | schema — explicit `seq`, no FKs, stored `canonical` |
| `5a_web/backend/src/ledger-link.js` | **pure core** — `buildLink`, `timeSql`, `signedFields`, `diffCanonical` |
| `5a_web/backend/src/services/ledger-service.js` | I/O shell — append, backfill, `verifyChain`, `assertTimeVector` |
| `5a_web/backend/test/ledger-link.test.js` | 25 tests, **no database required** |
| `5a_web/backend/tools/tamper-demo.mjs` | six scenarios, disposable database |
| `5a_web/backend/src/routes.js` | `GET /api/ledger/verify` (`CAP.VIEW`) |
| `5a_web/frontend/src/components/ActivityPage.jsx` | the audit-chain panel |
| edits to `db.js`, `index.js`, and 5 services | INT8 pin warning, boot check, append wiring |

### The pure/shell split was forced, not chosen

`ledger-service.js` imports `db.js` → `config.js`, which throws on a missing
`PG_PASS` **at import time**. The existing suite works around this by skipping
whole files unless `SDIGF_TEST_DB=1`. Applying that here would have meant the
frozen-vector and wire-name assertions only ran on a machine with a database —
the assertions that matter most being the ones most often skipped. So the pure
core moved to `src/ledger-link.js` beside `canon.js`, and the tests import that.

---

## 3 · VERIFIED LIVE vs VERIFIED IN SANDBOX

Never blur these.

### VERIFIED LIVE — on the deployed VPS stack

| Claim | Evidence |
|---|---|
| Schema applied to `sdigf_backend` | `BEGIN … CREATE TABLE … COMMIT`, TimescaleDB 2.29.2-pg16 |
| Zero foreign keys on `ledger` | `count(*) = 0` from `pg_constraint` |
| No default on `seq` | `column_default` empty |
| **Frozen time vectors** | `time_format_frozen = t` against the real database |
| `assertTimeVector()` gates startup | log line 2, after canonicalization, before MQTT |
| Backfill of pre-ledger history | `{ chained: 57, fromSeq: 1, toSeq: 57 }` |
| **Strict append through real services** | seq 58, 59 `COMMAND_ISSUED`, `backfilled = false` |
| `verifyChain` on the live chain | `ok true · length 59 · realTimeFrom 58 · unchained 0` |
| Endpoint + panel | ✅ rendering live; caveat-prominence fix `8f101f3` deployed as bundle `index-JPbHynHa.js` and captured as the Chapter 12 figure |

### VERIFIED IN SANDBOX — local Postgres 16.15, migrations 001–006

| Claim | Evidence |
|---|---|
| All five strict services chain | 7 links incl. a signature-bearing one at seq 6 |
| Cross-table reach | editing `config_approvals.signature` → `CONTENT_CHANGED`, diff names `signature.signature` |
| **E-stop publishes with the ledger broken** | `ledger` table renamed away → `published=true`, `chained=false`, MQTT fired, no throw |
| Gap is flagged, not silent | `UNCHAINED_EVENT` on restore, then reconciled `backfilled=true` |
| Six tamper scenarios | `tools/tamper-demo.mjs`, full output |
| Concurrent genesis appends | no fork; PK rejects the second |

**NOT verified live:** the e-stop path. Deferred — see §7.

---

## 4 · THE THREE SPECIFICATION POINTS THAT CAME FROM TESTING

Each looks like an oversight. Each was established by building and testing, not
by reasoning, and a build from the design alone would reproduce all three.

**1 — No foreign key on `ledger.event_id`.** A `REFERENCES` constraint makes
deleting a `server_events` row impossible, so the `EVENT_MISSING` check becomes
unreachable dead code — the database refusing the very tamper the check exists to
detect. `UNIQUE` is kept; it prevents two links claiming one event, a writer bug
rather than an attack. **Demonstrated by scenario 2**, which is only reachable
because the constraint is absent.

**2 — `seq` inserted explicitly, never `BIGSERIAL`.** `seq` is part of the hashed
content. A sequence does not reset when rows are deleted, so the column value can
silently diverge from the hashed value, and every later verification then fails
with a mismatch indistinguishable from tampering.

**3 — Check 5 and `realTimeFrom` computed outside the chain walk.** The walk
returns at its first failure. If they ran after it, an unchained event alongside
any other break would be invisible — the two things added specifically to close
gaps being exactly what does not run when verification actually fails.
**Demonstrated live in scenario 4**, where `PREV_MISMATCH` at seq 5 and
`unchained: 1` were both reported from one call.

### A fourth, found during this phase

**`time` must be a frozen string, and restoring a row through a JS `Date` breaks
it.** The tamper demo's first run reported the wrong failure at the wrong link,
with a diff naming `time`: `…331412Z` stored vs `…331000Z` current. Scenario 2's
restore had round-tripped the timestamp through `Date`, which holds milliseconds.
The ledger was right; the harness was not. Restores now use the same `to_char`
expression the ledger uses. The hazard is the precise one `time` is a string for.

### A fifth, found by testing COLD

**Preflight validated one connection target while the work used another.** The
tamper demo's preflight connects via its own `ADMIN` object, which defaults
`PG_HOST` to `127.0.0.1`. The script then set only `PG_DB` and let `config.js`
supply the rest — and `config.js` defaults `PG_HOST` to `sdigf-db`, the Docker
service name, correct inside the compose network and unresolvable outside it.
Preflight passed; the run then died on `getaddrinfo ENOTFOUND sdigf-db`.

**A preflight that validates a different target from the one the work uses is not
a preflight.** Fixed by propagating host, port and user, not just the database
name.

This would never have surfaced with `PG_HOST` set in the environment, which is
how every earlier run had been made. It appeared only on a genuinely cold run
from a fresh clone with nothing configured — the condition the fix was written
for in the first place.

---

## 5 · FIXED FACTS ABOUT THIS DEPLOYMENT

**`realTimeFrom = 58`.**

Links 1–57 are backfilled: they prove content integrity, but their ordering is
asserted after the fact. From link 58 forward, ordering was observed as it
happened. 58 and 59 are `COMMAND_ISSUED` events written through the real strict
path after the wiring deployed.

Backfill was run **before** the first real-time append, deliberately. The reverse
order would have put one real-time link at seq 1 and made `realTimeFrom` report
`1` — claiming real-time ordering from genesis while 57 of 58 links were
retrospective. `realTimeFrom` is a single number and can only mean "everything
from here forward was chained as it happened", which is true only if the
backfilled block sits at the bottom.

Frozen time expression, unchangeable without rewriting every hash:

```sql
to_char(time AT TIME ZONE 'UTC', 'YYYY-MM-DD"T"HH24:MI:SS.US"Z"')
```

Vectors: `2026-08-25 14:03:07.123456+03` → `2026-08-25T11:03:07.123456Z`;
`2026-01-02 03:04:05+00` → `2026-01-02T03:04:05.000000Z`.

Frozen wire names in the hashed object, differing from their source columns:
`gh` ← `gh_id`, `prev` ← `prev_hash`, `approval_id` ← `config_approvals.id`.

---

## 6 · THE HONEST BOUNDARY — AND A NEW FINDING BESIDE IT

### Scenario 6: consistent rewrite from genesis

An administrator deletes a range of events and rebuilds every subsequent link
using **the same `buildLink()` the legitimate writer uses**. Verification reports
`ok`. Measured:

```
BEFORE  9 links, ok
        1:KEY_REGISTERED  2:KEY_REGISTERED  3:APPROVAL_POLICY_CHANGED
        4:CONFIG_CREATED  5:CONFIG_PROPOSED  6:CONFIG_APPROVED
        7,8,9:COMMAND_ISSUED

ATTACK  erase CONFIG_CREATED, CONFIG_PROPOSED, CONFIG_APPROVED
        rebuild every link from genesis

AFTER   6 links, verification ok, unchained 0
```

Not a gap in the implementation. It is the boundary of what an **unanchored**
chain can prove: genesis anchors nothing outside the system, so a rewrite from
genesis is internally consistent by construction. External anchoring is named
future work and is not built.

### What survived — measured, not asserted

```
approval 1 by eng-omar (key eng-dea3007e)
    decision    : approve
    re-verified : VALID
    recomputed  : sha256(cfg_canonical) = eeda43af408f0128…
    stored      : cfg_hash             = eeda43af408f0128…
```

Ordering and narrative were destroyed and the chain still reports ok. Approvals
were not and cannot be: a signature never produced cannot be fabricated by
anyone, including an administrator with full database access, because the server
never held the private key.

### NEW FINDING — `realTimeFrom` is attacker-controlled after a rewrite

**Write this up beside scenario 6, not as a separate caveat.**

`realTimeFrom` is `MIN(seq) WHERE backfilled = false`. An administrator rebuilding
from genesis writes those rows, so they choose the flag — and therefore the
boundary. In the demo the rewritten chain reported `realTimeFrom = 1`: the
strongest possible claim, produced entirely by the attacker.

This does not weaken the design. `backfilled` was introduced so that verification
would not return uniform green across links proving genuinely different things —
a **disclosure**, never a tamper defence. But a reader who takes `realTimeFrom`
as a guarantee is misreading it, and the panel currently displays the number
without saying so.

It is the same limitation as scenario 6 reaching one layer further than the
demonstration showed: not only can a rewrite go undetected, the metadata
describing how much of the chain is trustworthy is itself rewritten. Stating it
strengthens the honest boundary rather than weakening it.

---

## 7 · OPEN ITEMS

**Live e-stop through the deployed stack — DEFERRED to Phase 02 bring-up.**
The best-effort path's most important property (publish survives ledger failure)
cannot be shown live without deliberately breaking the deployed audit trail. What
a live run would add is that the wiring works end to end — the weaker half. Worth
more during firmware bring-up, with a real device on the other end.

**Chapter 12 (the ledger) — unwritten.** Should close on scenario 6 with the
`realTimeFrom` finding beside it. A reviewer will construct that attack; the work
is stronger for having constructed it first.

**Chapter 10 §10.13 — STALE AND MUST BE CORRECTED.** It states that Phase 05a/05b
is not yet pushed to the public repo. It is, and has been throughout Phase 07.
The paragraph currently disclaims work a reader can verify — worse than silence.

**`realTimeFrom` disclosure in the panel** — the finding above is documented here
but the UI still presents the number without qualification.

---

## 8 · METHODOLOGY NOTES

**Two UI defects were found by looking at the rendered page, not by review.**

1. The grid mismatch that made an active emergency stop render as nothing.
2. The audit-chain caveat rendered in `--muted` while the result was bold
   `--text`. Reviewing the code shows a caveat block present and correctly
   worded; only the rendered page shows the eye landing on "No alteration
   detected" and leaving. **The requirement was satisfied at half strength, which
   is worse than not at all, because it looks addressed and a checklist passes.**
   Cause: inherited styling from surrounding panels rather than a decision.

**Two overstatements caught by deliberate re-reading, not by failure.** Neither
broke anything; both would have shipped.

1. *The half-strength caveat in the panel.* The scope block was present and
   correctly worded, but rendered in `--muted` against a bold result. Code review
   shows a compliant panel; only the rendered page shows the eye landing on "No
   alteration detected" and leaving.
2. *The scenario 6 survival claim.* The line "APPROVALS were not, and cannot be
   — a signature that was never produced cannot be fabricated by anyone" sat
   directly beneath a demonstration in which **the approval row was never
   attacked**. The attack deleted `server_events` rows only; `config_approvals`
   and `config_profiles` survived untouched, which is precisely why the signature
   could be re-verified. True in a narrow sense, read broader: the signature
   survived *a* destruction that did not target it, not *the* destruction. The
   real claim is narrower — **a past approval cannot be FORGED, never that it
   cannot be ERASED** — and is now stated on screen.

**These are the same class of error, and both were found by being asked to check
rather than by anything failing.** Together they are the evidence that
overstatement in this project has been caught by deliberate re-reading rather
than by accident — which is an argument for keeping the re-reading step, not for
trusting that it will not be needed next time.

**A React crash from an unread module contract.** `api.js` states in its header
that every call returns `{ data, error }` and never throws. The panel stored the
envelope as the payload; every field read `undefined`, the render threw, and
React unmounted the whole tree — a blank page. The `.catch()` written alongside
was dead code that could never fire. Exports were checked; the contract was not.

**Both `git add .` incidents were caught after the fact, not prevented.** Each
commit was clean, verified by a delete-filter check across the range. The rule
exists because that check is what gets skipped on a tired day, and the failure is
silent.

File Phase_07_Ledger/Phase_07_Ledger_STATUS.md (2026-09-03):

# PHASE 07 — STATUS FOR THE PROJECT PLANNER

**As of:** `1418eb6` on `origin/main`, working tree clean.
**Phase state:** CLOSED AND VERIFIED. One decision blocking follow-on work.

---

## 0 · ONE-PARAGRAPH SUMMARY

Phase 07 built a hash-chained audit ledger over `server_events`, with the
referenced approval signature resolved and hashed into each link so that
tampering with either table breaks the chain. It is deployed and live on the VPS.
Verification passes on the real chain: 59 links, `realTimeFrom = 58`, no
unchained events. The phase's thesis deliverable — a six-scenario tamper
demonstration — is committed and runs. All four pre-closure checks were run
against the live system rather than carried forward from the build session, and
one stale claim in the phase record was caught and corrected in the process.
**One item is blocked pending a decision: the tamper demo does not run from a
fresh clone without preparation, which matters because it is meant to be run in
front of an examiner.**

---

## 1 · WHAT PHASE 07 CONTRIBUTES — STATED NARROWLY

Phase 07 adds **nothing** to the trust model. It is not a second trust mechanism.

> **The chain-integrity check turns "erasable" into "detectably erasable."**

An administrator can still delete or rewrite session-attributed history. What
they cannot do is leave the chain consistent afterwards without rebuilding every
subsequent link. The record does not become unfalsifiable; it becomes falsifiable
only in ways that announce themselves.

Not a blockchain, not consensus, not distributed trust. One operator, one
database, one root credential.

**The Oracle Problem is stated rather than omitted.** No ledger can verify that a
sensor reading was honest, only that what was written has not been altered since.
Some chained events — retrospective local emergency stops — describe things the
server did not witness. The chain proves such a record was not altered after the
fact. It does not prove the originally reported time was true. That is a
different claim from the chain's usual one.

---

## 2 · THE BUILD, STEP BY STEP

The build order came from the phase brief. Each step was verifiable before the
next began.

### Step 1 — Schema (`db/006_ledger.sql`)

`ledger(seq, event_id, prev_hash, entry_hash, canonical, backfilled, created_at)`.

Four deliberate omissions, each of which looks like an oversight:

| Omission | Why |
|---|---|
| No FK `prev_hash → entry_hash` | a constraint that refuses to STORE a broken chain leaves verification nothing to detect |
| No FK `event_id → server_events(id)` | a REFERENCES constraint makes deleting an event impossible, so the `EVENT_MISSING` check becomes unreachable dead code |
| No `ON DELETE CASCADE` | a dangling link IS the evidence; cascading lets deletion tidy up after itself |
| `seq` explicit, not `BIGSERIAL` | `seq` is hashed content; a sequence does not reset on delete, so the column can silently diverge from the hashed value |

`canonical` is **stored, not recomputed** — an auditor sees the exact bytes that
were hashed, and a mismatch becomes diffable down to the field that changed.

Applied live to `sdigf_backend`. Three verification queries passed at the time
and again at closure.

### Step 2 — Service

Split into two files, and the split was **forced, not chosen**:

- `src/ledger-link.js` — pure core. `buildLink`, `timeSql`, `TIME_VECTORS`,
  `signedFields`, `diffCanonical`. Imports `canon.js` and nothing else.
- `src/services/ledger-service.js` — I/O shell. `appendToLedger`,
  `appendBestEffort`, `verifyChain`, `backfillLedger`, `getHead`,
  `assertTimeVector`.

**Why the split was necessary:** `ledger-service.js` imports `db.js` →
`config.js`, which throws on a missing `PG_PASS` **at import time**. The existing
test suite works around this by skipping whole files unless `SDIGF_TEST_DB=1`.
Applying that pattern here would have meant the frozen-vector assertions ran only
on a machine with a database — the most important tests being the most often
skipped. The pure core is importable with no infrastructure.

### Step 3 — Tests (`test/ledger-link.test.js`)

25 tests, no database required. Frozen wire names, frozen time format, the INT8
type-parser pin, determinism across key insertion order, strictness inherited
from `canon.js`.

### Step 4 — Wiring

Six write paths. Five strict, one best-effort.

| Service | Mode | Events covered |
|---|---|---|
| `config-service.recordEvent` | strict | five config lifecycle event types |
| `key-service` | strict | `KEY_REGISTERED` |
| `command-service` | strict | `COMMAND_ISSUED` |
| `approval-service` (policy) | strict | `APPROVAL_POLICY_CHANGED` |
| `approval-service` (vote) | strict | `CONFIG_APPROVED` — **the only signature-bearing link** |
| `estop-service` ×2 | **best-effort** | `ESTOP_TRIGGERED` / `ESTOP_CLEARED` |

Plus `index.js`: `assertTimeVector()` after `checkConnections()`, hard startup
failure, and a warning comment at `db.js`'s `setTypeParser(INT8, Number)` line.

**Every insert site was re-read before writing.** A concern that
`config-service`'s event logger used the pool directly turned out to be wrong —
it already took a transaction client and all five callers passed one, making it
the cheapest site rather than the most expensive. Flagging it at plan stage cost
nothing and would have caught the opposite.

### Step 5 — Backfill

57 pre-ledger events chained in one transaction, `backfilled = true`.
`{ chained: 57, fromSeq: 1, toSeq: 57 }`, then `verifyChain` → `ok`,
`realTimeFrom: null` (correct: nothing yet written in real time).

### Step 6 — Tamper demonstration (`tools/tamper-demo.mjs`)

Six scenarios against a disposable database. In `tools/` rather than `test/`
deliberately: scenario 6 correctly returns `ok` after a successful attack, which
under `node --test` would read as a passing test of a failing system.

### Step 7 — Endpoint and panel

`GET /api/ledger/verify`, guarded by `CAP.VIEW` — all three roles including
admin. The chain defends against an admin **altering** it, not **reading** it;
hiding the result would protect nothing while making the audit visible to only
some staff.

The response carries a `claim` block in the payload, not only the UI, so any
future consumer (Phase 05c MCP server, a thesis figure script) inherits the
bounded claim. A caller rendering `ok` without it is visibly discarding
something.

---

## 3 · VERIFIED LIVE vs VERIFIED IN SANDBOX

**Never blur these.**

### VERIFIED LIVE — deployed VPS stack

| Claim | Evidence |
|---|---|
| Schema applied | `BEGIN … CREATE TABLE … COMMIT` on TimescaleDB 2.29.2-pg16 |
| Zero foreign keys | `SELECT … contype='f'` → 0 rows |
| No default on `seq` | `column_default` empty |
| UNIQUE constraints retained | `UNIQUE (entry_hash)`, `UNIQUE (event_id)` |
| Frozen time vectors | `time_format_frozen = t` against the real database |
| `assertTimeVector()` gates startup | log line 2, after canonicalization, before MQTT |
| Backfill | `{ chained: 57, fromSeq: 1, toSeq: 57 }` |
| Strict append through real services | seq 58, 59 `COMMAND_ISSUED`, `backfilled = false` |
| Chain state | `59 links · min 1 · max 59 · 57 backfilled` |
| Endpoint | `ok true · verifiedThrough 59 · realTimeFrom 58 · unchainedEvents [] · claim intact` |
| Deployed bundle | `index-JPbHynHa.js` |
| Panel figure | captured, caveat at full weight |

**Cross-check worth noting:** the endpoint's `head.entryHash` begins
`5be47bfed5f3e157`, matching the seq-59 hash read directly from the table. Two
independent paths, same value.

### VERIFIED IN SANDBOX — local Postgres 16.15

| Claim | Evidence |
|---|---|
| All five strict services chain | 7 links incl. a signature-bearing one at seq 6 |
| Cross-table reach | editing `config_approvals.signature` → `CONTENT_CHANGED`, diff names `signature.signature` |
| **E-stop publishes with the ledger broken** | `ledger` renamed away → `published=true`, `chained=false`, MQTT fired, no throw |
| Gap flagged, not silent | `UNCHAINED_EVENT`, then reconciled `backfilled=true` |
| Six tamper scenarios | full output |
| Concurrent genesis appends | no fork; PK rejects the second |
| Tests without infrastructure | 88 pass, 0 skipped, `SDIGF_TEST_DB` unset |

**NOT verified live: the e-stop path.** Its most important property — publish
survives ledger failure — cannot be shown live without deliberately breaking the
deployed audit trail. Deferred to Phase 02 bring-up, where a real device makes it
worth more.

---

## 4 · SPECIFICATION POINTS THAT CAME FROM TESTING, NOT REASONING

Three came from the brief. A fourth was found during this phase.

**1 — No foreign key on `ledger.event_id`.** Same mistake as `prev_hash`, one
column over. Demonstrated by scenario 2, which is only reachable because the
constraint is absent.

**2 — `seq` inserted explicitly.** A sequence does not reset when rows are
deleted, so the column value can diverge from the hashed value, and every later
verification fails indistinguishably from tampering.

**3 — Check 5 and `realTimeFrom` computed outside the chain walk.** The walk
returns at its first failure; a check running after it would be missing exactly
when verification fails. Demonstrated live in scenario 4, which reports
`PREV_MISMATCH` at seq 5 **and** `unchained events 4` from one call.

**4 — NEW: restoring a row through a JS `Date` loses microseconds.** The tamper
demo's first run reported the wrong failure at the wrong link, with a diff naming
`time`: `…331412Z` stored vs `…331000Z` current. Scenario 2's restore had
round-tripped the timestamp through `Date`, which holds milliseconds. **The
ledger was right; the harness was not.** This is the precise hazard `time` is a
frozen string for. Restores now use the same `to_char` expression the ledger
uses, and each destructive scenario prints a `[restored byte-exactly]`
confirmation so a damaged fixture cannot masquerade as a finding.

---

## 5 · FIXED FACTS ABOUT THIS DEPLOYMENT

**`realTimeFrom = 58`.**

Links 1–57 are backfilled: content integrity proven, ordering asserted after the
fact. From 58 forward, ordering was observed as it happened.

**Backfill ran before the first real-time append, deliberately.** The reverse
order would have put one real-time link at seq 1 and made `realTimeFrom` report
`1` — claiming real-time ordering from genesis while 57 of 58 links were
retrospective. `realTimeFrom` is `MIN(seq) WHERE backfilled = false`, a single
number, and only means what it says if the backfilled block sits at the bottom.

Frozen time expression, unchangeable without rewriting every hash:

```sql
to_char(time AT TIME ZONE 'UTC', 'YYYY-MM-DD"T"HH24:MI:SS.US"Z"')
```

Vectors: `2026-08-25 14:03:07.123456+03` → `2026-08-25T11:03:07.123456Z` ·
`2026-01-02 03:04:05+00` → `2026-01-02T03:04:05.000000Z`.

Frozen wire names, differing from their source columns: `gh` ← `gh_id`,
`prev` ← `prev_hash`, `approval_id` ← `config_approvals.id`.

---

## 6 · THE HONEST BOUNDARY

### Scenario 6 — consistent rewrite from genesis

An administrator deletes a range of events and rebuilds every subsequent link
using **the same `buildLink()` the legitimate writer uses**. Verification reports
`ok`.

```
BEFORE  9 links, ok
        1:KEY_REGISTERED  2:KEY_REGISTERED  3:APPROVAL_POLICY_CHANGED
        4:CONFIG_CREATED  5:CONFIG_PROPOSED  6:CONFIG_APPROVED
        7,8,9:COMMAND_ISSUED

ATTACK  erase CONFIG_CREATED, CONFIG_PROPOSED, CONFIG_APPROVED
        rebuild every link from genesis

AFTER   6 links, verification ok, unchained 0
        3 links and 3 events are gone.

WHAT SURVIVED
  approval 1 by eng-omar (key eng-f7b45be3)
      re-verified : VALID
      recomputed  : sha256(cfg_canonical) = eeda43af408f01281455e59b341d9620…
      stored      : cfg_hash             = eeda43af408f01281455e59b341d9620…
```

Not a gap in the implementation. It is the boundary of what an **unanchored**
chain can prove: genesis anchors nothing outside the system, so a rewrite from
genesis is internally consistent by construction. External anchoring is named
future work and is not built.

Both halves of *"history can be destroyed, approvals cannot be invented"* are
**measured, not asserted** — the surviving signature is re-verified against its
registered public key by the script itself.

### `realTimeFrom` is attacker-controlled after a rewrite

An administrator rebuilding from genesis writes those rows and therefore chooses
the `backfilled` flag — and so the boundary. In the demonstration the rewritten
chain reported `realTimeFrom = 1`: the strongest possible claim, produced
entirely by the attacker.

This does not weaken the design. `backfilled` exists so verification does not
return uniform green across links proving genuinely different things — a
**disclosure**, never a tamper defence. But a reader who takes `realTimeFrom` as
a guarantee is misreading it.

**Write this beside scenario 6 in Chapter 12, not as a separate caveat.** It is
the same limitation reaching one layer further: not only can a rewrite go
undetected, the metadata describing how much of the chain is trustworthy is
itself rewritten.

---

## 7 · THE PANEL, AND WHAT NEARLY UNDID THE PHASE

The brief's step 7 said *"a dashboard panel showing chain head, verify result and
realTimeFrom."* Built literally, that is a green checkmark reading "Chain OK" —
asserting exactly what scenario 6 disproves.

Four requirements, supplied mid-phase rather than by the brief:

1. never display the result alone
2. always show `realTimeFrom` with its meaning in words
3. state the scope of the claim in the panel, not a tooltip
4. no green-checkmark iconography — full-saturation green stays reserved for
   reading quality

**Even then it landed at half strength.** The caveat rendered in `--muted`
against a bold `--text` result. On review the code shows a caveat block present
and correctly worded; only the rendered page shows the eye landing on "No
alteration detected" and leaving. **The requirement was satisfied at half
strength, which is worse than not at all, because it looks addressed and a
checklist passes.** Cause: inherited styling from surrounding panels rather than
a decision. Fixed in `8f101f3`, now deployed and photographed.

**Lesson for future briefs:** a brief that carefully bounds a claim for eight
sections and then specifies the UI in one line will have that care undone by the
interface. This applies immediately to Phase 05c, where an LLM will phrase claims
about system state in natural language — the least constrained surface in the
project.

---

## 8 · CLOSURE VERIFICATION

Four items were run against the live system rather than reported from memory.

| # | Item | Result |
|---|---|---|
| 1 | Local `git status` | clean, HEAD = `origin/main` at `1418eb6` |
| 2 | Three schema queries against **live** `sdigf_backend` | all three pass — no manual `ALTER TABLE` undid them |
| 3 | Live chain + endpoint | `59 / 1 / 59 / 57`, full JSON body captured |
| 4 | Redeploy + panel capture | `index-JPbHynHa.js`, figure captured |

**The verification caught a sixth stale claim.** The phase record listed the
endpoint and panel as VERIFIED LIVE, but that row was written before `8f101f3` —
the deployed panel at the time was still the half-strength version. Corrected to
*"panel rendering live as of `1d22417`; caveat-prominence fix `8f101f3`
committed, deployment unconfirmed."* That fix is now deployed, so the row can be
promoted to fully verified when the record is next touched.

Three of the seven verification checks depended on the live system and were
marked **NOT VERIFIED** rather than softened. Reporting them as passed on the
strength of an earlier session would have been precisely the failure the
verification instruction guards against.

---

## 9 · WHAT IS BLOCKING ME

**One decision.**

`tamper-demo.mjs` does **not** run from a fresh clone. Tested on a clean clone of
`1418eb6`:

| Condition | Result |
|---|---|
| No Postgres running | `Error: connect ECONNREFUSED 127.0.0.1:5432` + raw stack trace |
| Postgres up, no `PG_PASS` | `SASL: client password must be a string` + raw stack trace |
| `PG_PASS` set | runs correctly, all six scenarios |

`node_modules` is committed, so `pg` imports fine — the blocker is purely the
database connection.

This matters because the demo is intended to be **run live in front of an
examiner**. A red stack trace reads as broken software rather than a missing
prerequisite.

**Two options:**

- **Preflight check** — ~15 lines. Attempt the admin connection first; on failure
  print a plain-language message naming exactly what to do, then exit cleanly.
  No stack trace. Safe to run cold.
- **README only** — no code change; the ugly failure mode remains if the step is
  missed.

**My recommendation: preflight.** The script's entire purpose is to be run in
front of someone judging the work by what appears on screen. It is also
consistent with the phase: `config.js` fails at startup rather than on first
request, `assertTimeVector` refuses to boot rather than warn.

**Awaiting: preflight, or README only?**

---

## 10 · QUEUED BEHIND THAT DECISION

**A — Non-technical README** in `Phase_07_Ledger/`, answering the examiner's
three questions in plain language:

- *"What is the source code of the blockchain you performed?"* — names the four
  source files and what each does
- *"How did you perform it?"* — the mechanism in plain terms
- *"Do you store any data on it?"* — the data/evidence split: config values stay
  in `config_profiles`; only the hash and signature cross into the chain, which
  is why editing the database breaks the match

Plus a plain statement that this is a hash-chained log and **not** a blockchain,
with the reason.

**B — The fresh-clone fix or documented step**, per the decision above.

**C — My view on whether scenario 6's console output is print-ready** as a thesis
figure verbatim, or needs reformatting.

---

## 11 · OPEN ITEMS, NOT BLOCKING

| Item | State |
|---|---|
| Live e-stop through the deployed stack | deferred to Phase 02 bring-up |
| Chapter 12 (the ledger) | unwritten; the phase record is structured to become it |
| Chapter 10 §10.13 | **stale** — still claims Phase 05a/05b is unpushed; it has been public throughout |
| Phase record's panel row | can be promoted to fully verified now that `8f101f3` is deployed |
| `Phase_07_Ledger/` orientation note | folder holds documentation pointing at code under `Phase_05_Backend_Dashboard/5a_web/` |

---

## 12 · WHAT PHASE 07 DID NOT MOVE

**Phase 02/03 firmware remains unwritten and blocked on ESP32 wiring.** It is the
project's critical path. Phase 07 was server-tier work done alongside that
blocker, not against it. Worth stating plainly in the next plan.

---

## 13 · METHODOLOGY NOTES

**Two UI defects found by looking at the rendered page, not by review.** The grid
mismatch that made an active emergency stop render as nothing, and the audit
caveat rendered dim against a bold result. Both invisible in code review.

**A React crash from an unread module contract.** `api.js` states in its header
that every call returns `{ data, error }` and never throws. The panel stored the
envelope as the payload; every field read `undefined`, the render threw, and
React unmounted the whole tree — a blank page. The `.catch()` written alongside
was dead code that could never fire. Exports were checked; the contract was not.

**Both `git add .` incidents were caught after the fact, not prevented.** Each
commit was clean, verified by a delete-filter check across the range. The rule
exists because that check is what gets skipped on a tired day, and the failure is
silent.

**One planning error, caught before execution.** Backfill ordering: the operator
was initially told to issue a command before running `backfillLedger()`, which
would have produced `realTimeFrom = 1` on the live chain. Corrected before it
ran. This is recorded here because §5 states the ordering as settled without
noting it was nearly wrong.

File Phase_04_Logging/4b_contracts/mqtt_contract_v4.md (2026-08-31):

# SDIGF — MQTT Contract v4

**Project:** Smart Decentralized Greenhouse (SDIGF)
**Status:** COMPLETE — Parts 1–4 signed off, edge verification amendment applied
**Last updated:** 2026-08-25
**Supersedes:** `mqtt_contract_v3.md` (superseded copies live in `old/`)
**Location:** `Phase_04_Logging/4b_contracts/mqtt_contract_v4.md`

> **This document is the interface between the edge tier and the server tier.**
>
> **Document version vs. topic version.** This is document revision **v4**. The topic namespace
> remains **`sdigf/v1/...`** and the envelope field `v` remains **`1`**. The two are deliberately
> independent: the topic version changes only on a breaking wire change, whereas the document
> revises whenever the specification is clarified or extended. v4 extends `down/config` and
> `up/ack` with fields that were absent in v3; an edge running v3 firmware still parses a v4
> `down/config` correctly, because the added fields are additive and the removed one
> (`cfg`) is replaced by a string carrying identical content — see §3.6.
>
> | Implementation | Role |
> |---|---|
> | ESP32 firmware (Phase 02–03) | publishes telemetry, consumes config, enforces the safety envelope, **verifies approval signatures** |
> | MQTT→DB bridge (Phase 04d) | consumes everything, writes to Postgres. Read-only: never publishes |
> | REST backend (Phase 05a) | publishes config and commands, computes and verifies the canonical hash |
> | Browser (Phase 05b) | computes the canonical hash and signs it |
> | Mock edge simulator (Step 04c) | stands in for the ESP32 until firmware exists |

> **What changed in v4, in one paragraph.** The ESP32 can now verify the threshold approval
> signatures on a configuration before applying it. In v3 it could not, which meant the
> cryptographic chain of custody ended at the backend service: anyone holding the
> `sdigf-backend` broker credential could publish an arbitrary config and the edge would apply it
> if the values were physically safe. v4 closes that gap by publishing the exact canonical string
> alongside its hash and signatures, so the edge verifies over bytes it was handed and needs no
> canonicalization logic of its own. Firmware implementation is a Phase 03 deliverable and may or
> may not ship; the fields are reserved now because 05b's key storage depends on them and
> retrofitting a frozen contract afterwards is far more expensive than reserving space today.

---

## 1. Topic tree

```
sdigf/v1/gh1/up/telemetry      ESP32 → server
sdigf/v1/gh1/up/actuators      ESP32 → server
sdigf/v1/gh1/up/health         ESP32 → server
sdigf/v1/gh1/up/ack            ESP32 → server
sdigf/v1/gh1/status            ESP32 → server  (last will)

sdigf/v1/gh1/down/config       server → ESP32
sdigf/v1/gh1/down/cmd          server → ESP32
sdigf/v1/gh1/down/keys         server → ESP32  (RESERVED — see §3.8)
sdigf/v1/gh1/down/estop        server → ESP32  (see §3.9)
```

**`v1` in the path.** When the contract changes, `v2` topics can run alongside `v1` during
migration rather than breaking every client simultaneously. Costs nothing now.

**`gh1` as a device slot.** A second greenhouse becomes `gh2` with no redesign. The bridge
subscribes with a wildcard: `sdigf/v1/+/up/telemetry`.

**`up` / `down` in the path.** Direction is visible in the topic itself, which makes Phase 05b
ACLs nearly trivial: `sdigf-edge` gets publish on `up/#` and subscribe on `down/#`, nothing else.

### QoS and retain

Governing rule: **retain state, do not retain events.**

| Topic | QoS | Retained | Reasoning |
|---|---|---|---|
| `up/telemetry` | 0 | no | A stream. Losing one reading is harmless — the next arrives shortly. QoS 1 would fill the ESP32 inflight buffer whenever the broker is slow. |
| `up/actuators` | 1 | **yes** | Current state. A freshly connected dashboard must see what is on right now. |
| `up/health` | 0 | **yes** | Current state, but not worth a retry. |
| `up/ack` | 1 | no | An event — and the one that proves what the hardware actually applied. Must not be lost. |
| `status` | 1 | **yes** | A last will must be retained, or a late subscriber never learns the edge is down. |
| `down/config` | 1 | **yes** | The reconnect design depends on this. See the retention caveat below. |
| `down/cmd` | 1 | no | An event with a TTL. Retaining it would re-fire on every reconnect. |
| `down/estop` | 1 | **yes** | State, not an event. A controller rebooting into a halted greenhouse must come back halted. |
| `down/keys` | 1 | **yes** | Reserved. Current state — a device must receive the trusted key list on connect without the server detecting the reconnection. |

> **⚠ Retention caveat — corrected 2026-08-25.** An earlier revision of this table claimed
> retention was verified across a broker restart. **It was not.** Only *client* reconnect had been
> tested. When the broker restart was finally tested on 2026-08-25 it **failed**: EMQX defaults
> `retainer.backend.storage_type` to `ram`, so retained messages were held in memory only and
> destroyed on restart. Fixed by setting `disc`, and re-verified by publishing a retained message,
> restarting the broker, and confirming survival.
>
> The deeper point outlives the setting: **retained messages are broker-held state, and broker
> state is not durable by default.** The server must therefore be able to reconstruct every
> retained topic from its own database. Phase 05a republishes the current approved config on
> startup and on broker reconnect, treating the retained message as a cache rather than a source
> of truth. This is the same reasoning as the edge safety envelope — do not assume infrastructure
> you do not control got it right.

### Batched telemetry

All sensor readings travel in **one message**, not one topic per sensor.

Rationale — nothing in the system ever wants a single sensor in isolation:

- The bridge writes every reading to one table with one timestamp.
- The dashboard renders all gauges together.
- The control loop reads temperature **and** humidity together to evaluate Conflict A. Split
  topics would require pairing messages that arrived at slightly different times — a bug
  waiting to happen.
- The ESP32 reads all sensors in one loop pass anyway; publishing separately would mean many
  packets each carrying a copy of the same timestamp.

**Revisit if:** a single greenhouse ever exceeds roughly 30–40 readings, at which point the
batch would strain the ESP32 MQTT buffer.

---

## 2. Shared envelope

Every edge→server message carries these, so the bridge can validate uniformly.

| Field | Type | Meaning |
|---|---|---|
| `v` | int | **Schema** version — not config version. Bump when payload shape changes. |
| `ts` | int | Unix epoch seconds, device clock |
| `tsq` | string | Timestamp quality: `ntp` (synced) or `boot` (seconds since boot; wall-clock meaningless) |
| `seq` | int | Monotonic counter, resets on reboot. Lets the server detect gaps. |

### Two implementation constraints

**Timestamp trust.** The ESP32 has no RTC. Before NTP syncs, `ts` is not wall-clock time —
hence `tsq`. **The bridge must record both the device timestamp and its own receive time**, and
prefer server time when `tsq` is `boot`. Without this, 1970-dated rows land in the thesis dataset.

**MQTT buffer size.** Arduino `PubSubClient` defaults to a **256-byte** buffer and fails
*silently* when exceeded — the publish simply does not happen. Telemetry is ~480 bytes.
**Phase 03 firmware must call `setBufferSize(2048)`.** Required, not advice. (See §3.6 — measured `down/config` payloads reach 1,556 B at four signatures. This line previously said 1024, which contradicted §3.6 and was too small.)

### Bridge obligations

**Deduplication is mandatory.** The Phase 04d bridge must enforce uniqueness on
`(greenhouse_id, seq, sensor_name)`. Two mechanisms produce duplicates in normal operation:
QoS 1 redelivery when an acknowledgement is lost, and republication after an edge reconnect.
Duplicate rows skew every aggregate silently — a conflict-frequency count computed over
duplicated data is simply wrong, with nothing to indicate it. A unique constraint costs almost
nothing and makes the failure impossible rather than merely unlikely.

`seq` resets to zero on reboot, so the constraint alone is not sufficient across restarts. The
bridge should treat a `seq` lower than the last one seen as a reboot and record it as such,
rather than rejecting the row.

**Retention must not silently delete evidence.** The database schema currently retains
telemetry for 90 days. If data collection begins well before the thesis is written, that policy
will remove early observations without any warning. Either extend retention to cover the full
project timeline, or — better — export a frozen dataset table that no retention policy touches.
A thesis dataset should not be something a background job can quietly alter.

**Telemetry interval: 30 seconds.** Fixed. `sys.telemetry_interval_s` defaults to `30`, and the
mock must be updated to match.

The reasoning matters, because both obvious answers are wrong. At 10 s most of what is stored is
sensor noise around an unchanged value — air temperature in a small sealed enclosure has a time
constant measured in minutes, and humidity is slower still. But 60 s would alias the very thing
Phase 04 exists to measure: the conflict-frequency question is about **actuator oscillation**, a
fan cycling against a humidifier, which happens considerably faster than the underlying physics.
Sampling at 60 s could show a steady state that never existed.

30 s is three times less storage than 10 s while still resolving oscillation. The edge control
loop is unaffected — only the publish rate changes.

---

## 3. Payload schemas

### 3.1 `up/telemetry` — QoS 0, not retained

```json
{
  "v": 1,
  "ts": 1756036800,
  "tsq": "ntp",
  "seq": 142,
  "r": {
    "temp_in":   {"val": 24.3,   "q": "ok"},
    "temp_out":  {"val": 19.8,   "q": "ok"},
    "press_in":  {"val": 1012.4, "q": "ok"},
    "press_out": {"val": 1012.1, "q": "ok"},
    "hum_in":    {"val": 58,     "q": "ok"},
    "hum_out":   {"val": null,   "q": "fail"},
    "aq":        {"val": 142,    "q": "ok"},
    "light_in":  {"val": 812,    "q": "ok"},
    "light_out": {"val": 2140,   "q": "ok"},
    "soil":      {"val": 41,     "q": "stale"},
    "water":     {"val": 78,     "q": "ok"}
  }
}
```

| Key | Source | Type | Unit | Notes |
|---|---|---|---|---|
| `temp_in` | BMP280 @0x76 | float | °C | 1 decimal |
| `temp_out` | BMP280 @0x77 | float | °C | 1 decimal |
| `press_in` | BMP280 @0x76 | float | hPa | 1 decimal |
| `press_out` | BMP280 @0x77 | float | hPa | 1 decimal |
| `hum_in` | DHT11 GPIO26 | int | %RH | integer only — sensor limitation |
| `hum_out` | DHT11 GPIO27 | int | %RH | integer only |
| `aq` | MQ135 GPIO32 | int | raw ADC | **relative trend, not ppm** |
| `light_in` | LDR GPIO36 | int | raw ADC | 0–4095 |
| `light_out` | LDR GPIO39 | int | raw ADC | 0–4095 |
| `soil` | FC-28 GPIO34 | int | % | mapped from ADC |
| `water` | GPIO35 | int | % | mapped from ADC |

> **Note.** Telemetry values are *not* hashed or signed, so floats are acceptable here. The
> integer-only rule in Part 4 applies to the **config payload** only.

#### Quality values

| `q` | Meaning | `val` | Control loop should |
|---|---|---|---|
| `ok` | Fresh and within plausible range | number | use it |
| `stale` | Last good value, older than `sys.stale_after_s` | last known number | use with caution, or fall back |
| `fail` | Read error, or outside physical bounds | `null` | **not** use it — fail safe |
| `init` | Never successfully read since boot | `null` | not use it |

`init` is distinct from `fail` on purpose: a DHT11 needs a couple of seconds before its first
reading, and without a separate state it is impossible to distinguish "broken" from "not asked
yet." That distinction appears in the logs after every reboot.

**The null rule.** When `q` is `fail` or `init`, `val` is always `null` — never `0` or `-127`.
Sentinel values leak into averages and quietly corrupt the dataset. `null` maps directly to
SQL `NULL` and is excluded from aggregates automatically.

**Why raw ADC for light and air quality.** Neither is calibrated. `aq` is explicitly a relative
trend per the project's stated caveats; calibrating an LDR to lux would invent precision that
does not exist. Store raw, interpret during analysis — the defensible choice academically.

---
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

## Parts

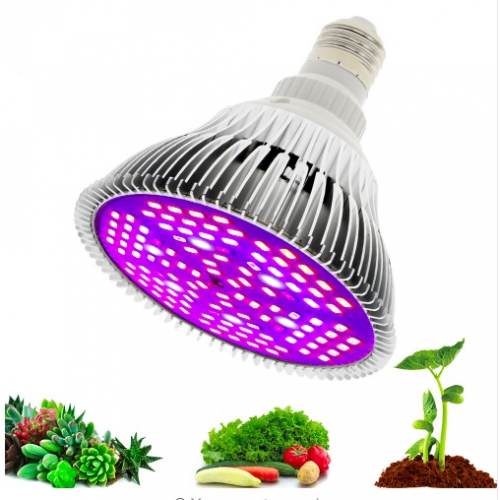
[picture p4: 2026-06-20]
Hardware Components/18) Led Grow Light.png

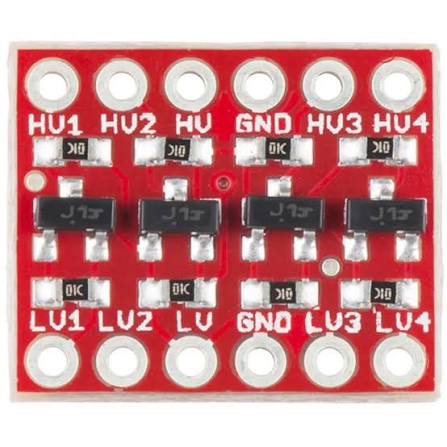
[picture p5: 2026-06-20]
Hardware Components/10) Bidirectional Logic Level Converter A.png

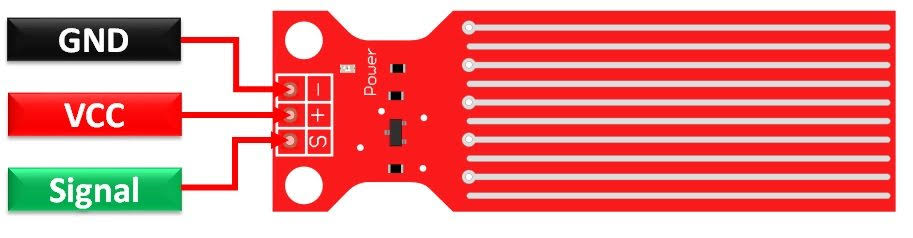
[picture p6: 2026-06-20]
Hardware Components/8) Water Sensor.jpg

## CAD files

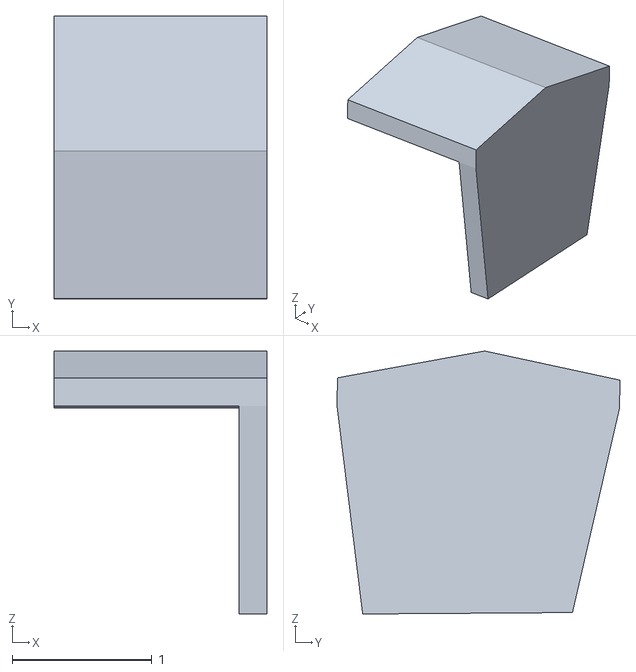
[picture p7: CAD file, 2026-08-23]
Phase_00_Prototype/3D/P1 x4.stl
1.52 x 2.02 x 1.88

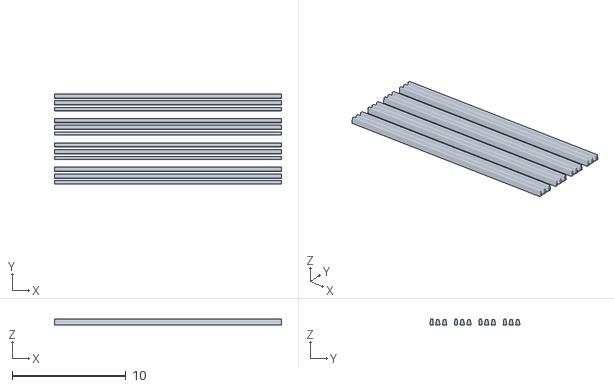
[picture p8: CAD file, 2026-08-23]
Phase_00_Prototype/3D/Addition.stl
20.0 x 7.93 x 0.498

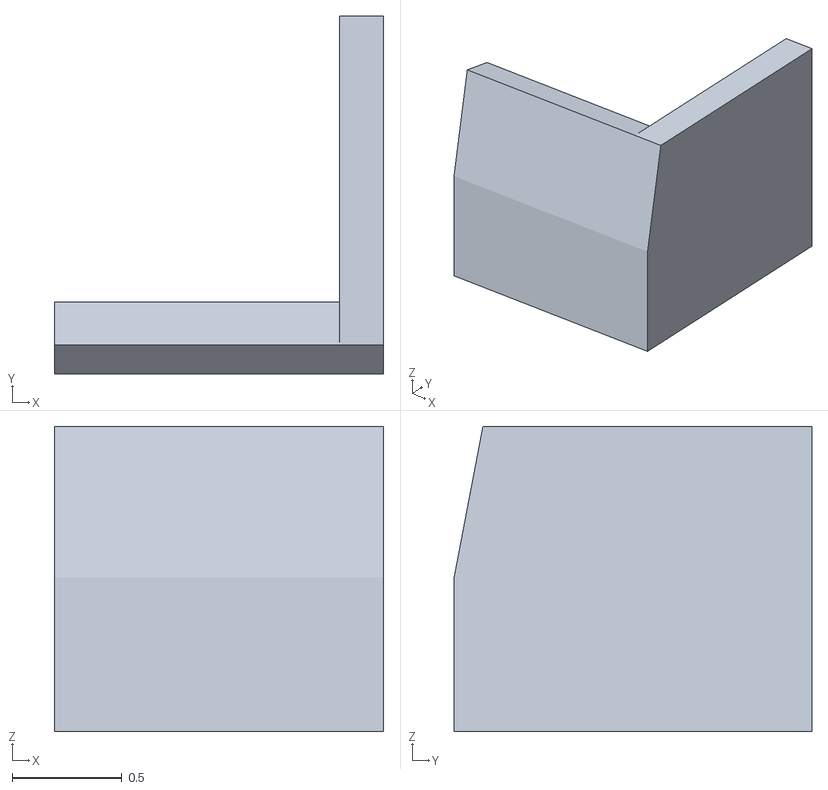
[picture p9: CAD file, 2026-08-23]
Phase_00_Prototype/3D/P4 x4.stl
1.50 x 1.63 x 1.39

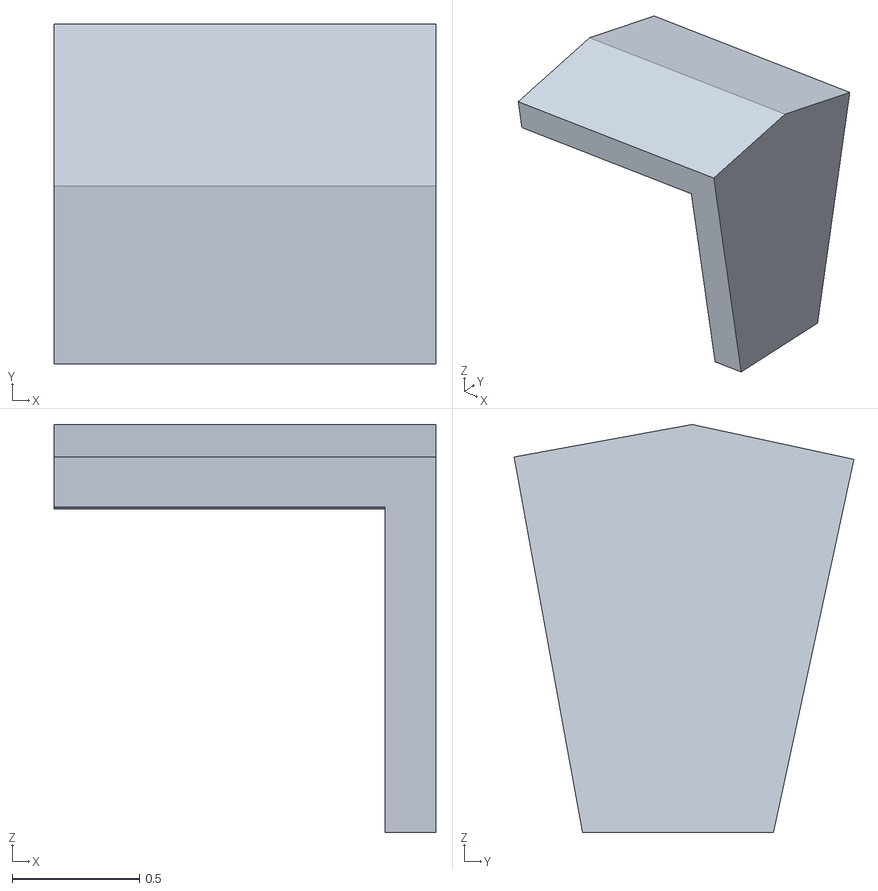
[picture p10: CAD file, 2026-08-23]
Phase_00_Prototype/3D/P2 x4.stl
1.50 x 1.34 x 1.60

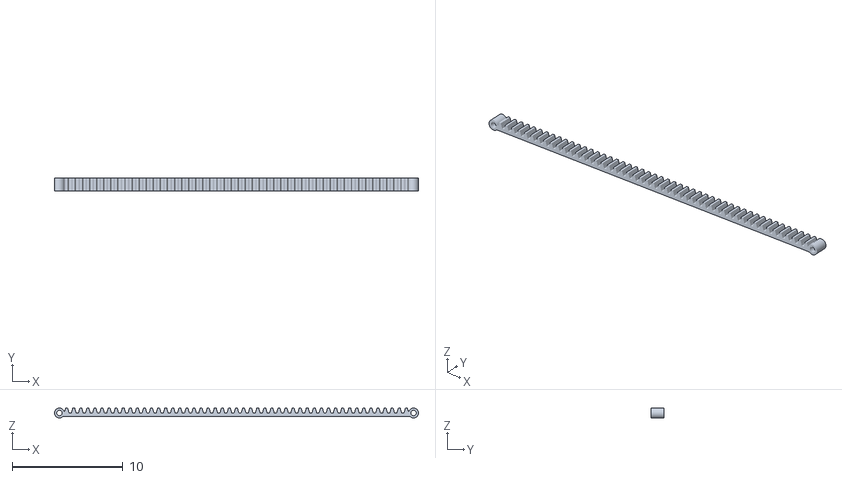
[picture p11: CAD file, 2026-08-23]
Phase_00_Prototype/3D/truc1 Extended (2).stl
32.9 x 1.18 x 0.9

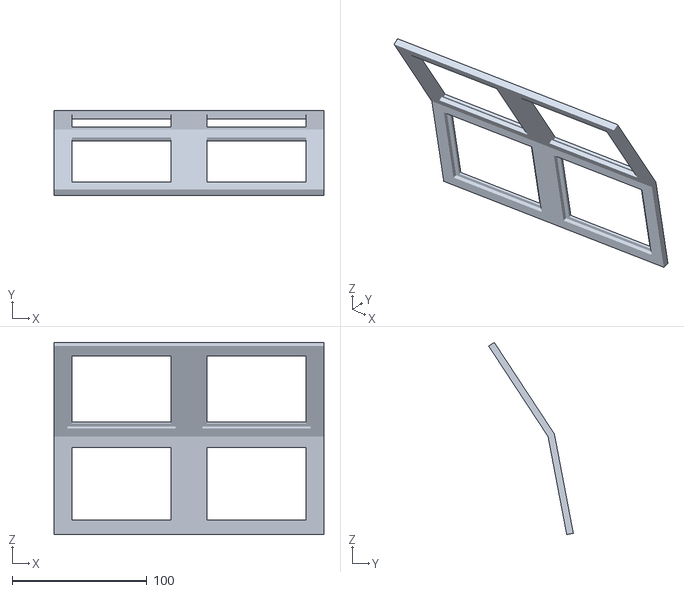
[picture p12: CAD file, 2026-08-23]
Phase_00_Prototype/3D/Print Structure B x4 (2).stl
200.0 x 62.8 x 142.4

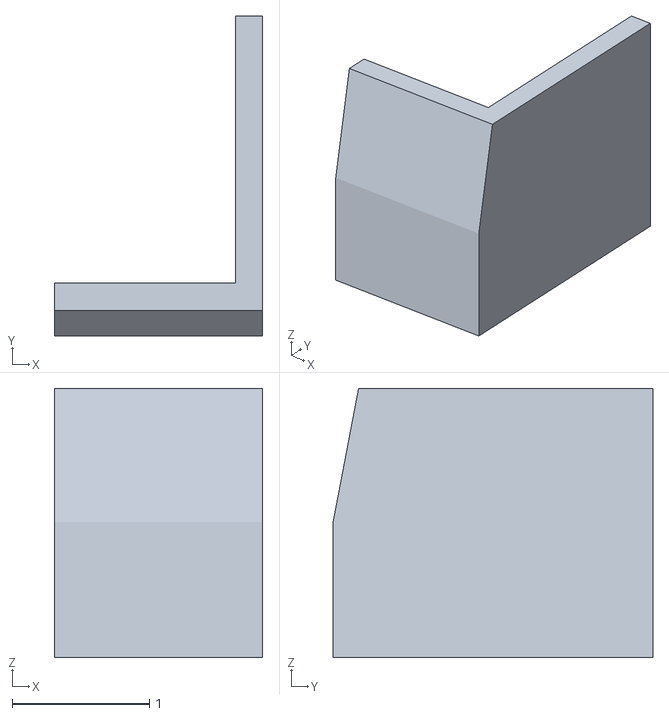
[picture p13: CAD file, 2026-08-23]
Phase_00_Prototype/3D/P3 x4.stl
1.52 x 2.33 x 1.96

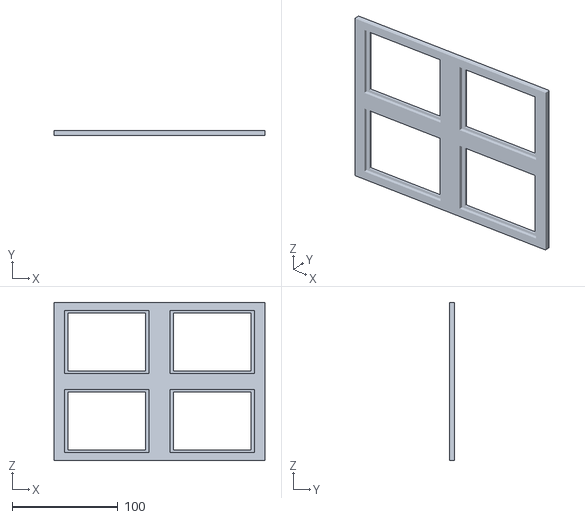
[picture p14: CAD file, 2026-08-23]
Phase_00_Prototype/3D/Print Structure A x4 (2).stl
200.0 x 5.00 x 150.0

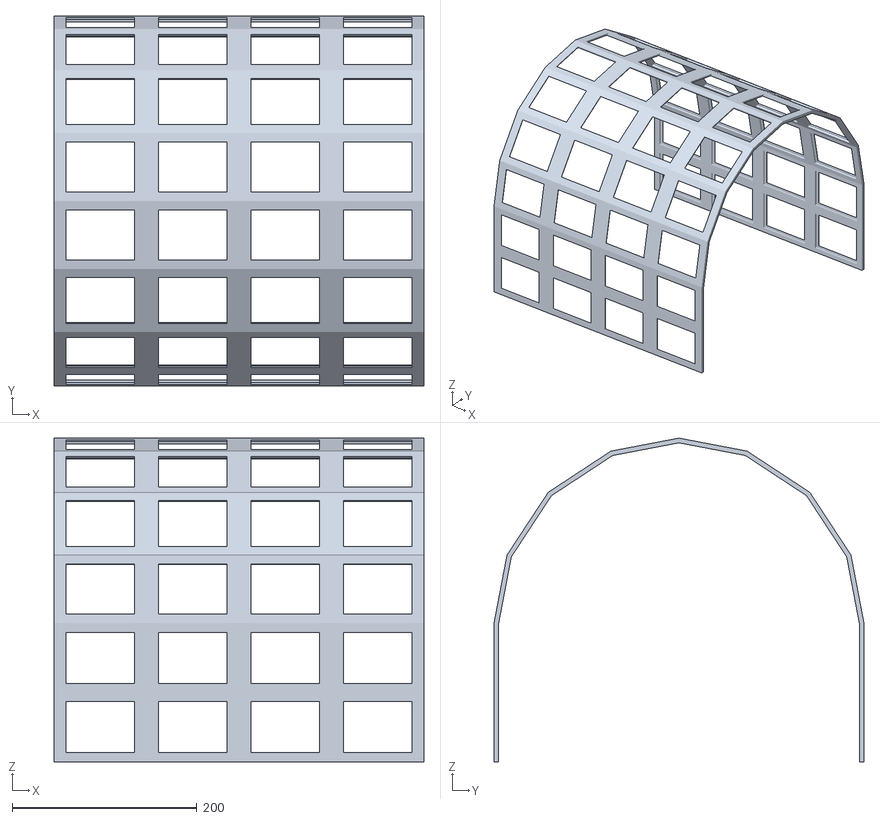
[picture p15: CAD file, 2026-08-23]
Phase_00_Prototype/3D/Print Structure (2).stl
400.0 x 400.0 x 350.0

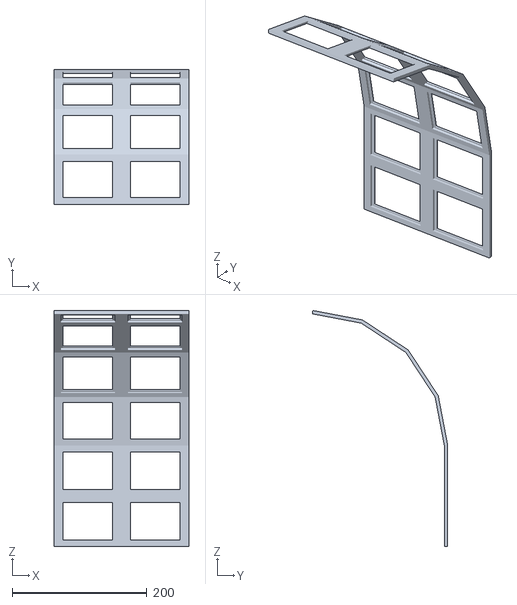
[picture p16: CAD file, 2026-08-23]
Phase_00_Prototype/3D/Print Structure x4 (2).stl
200.0 x 200.9 x 350.0

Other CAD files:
Phase_00_Prototype/3D/Print Structure C x4 (2).stl

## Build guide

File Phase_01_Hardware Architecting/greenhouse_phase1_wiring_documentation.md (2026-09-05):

# Smart Decentralized Greenhouse — Hardware & Wiring Documentation

**Phase 1 — Wiring and Hardware Bring-up**
**Controller:** ESP32-WROOM-32E
**Document scope:** Complete electrical specification from the 220–230 V mains source through every ESP32 pin, for Phase 1 only. The system also includes the ESP32-CAM as a separate node — it has no data connection to the main controller, though it draws power from the same 5 V supply; it appears here at inventory level only.

| Field | Value |
|---|---|
| Document version | 1.8 |
| Date | 6 September 2026 |
| Phase | 1 (hardware bring-up) |
| Status | Wiring locked — ready to build |

---

## Table of Contents

1. [Introduction](#1-introduction)
2. [System Overview](#2-system-overview)
3. [Hardware Components & Specifications](#3-hardware-components--specifications)
4. [Electrical Wiring Color Convention](#4-electrical-wiring-color-convention)
5. [Power Supply Architecture](#5-power-supply-architecture)
6. [Grounding Topology](#6-grounding-topology)
7. [ESP32-WROOM-32E — Pin Architecture & Wiring](#7-esp32-wroom-32e--pin-architecture--wiring)
   - 7.1 Pin reference (general)
   - 7.2 This project's pin use
   - 7.3 Analog Sensors
   - 7.4 Digital Sensors
   - 7.5 I2C Bus
   - 7.6 Actuators & Outputs (Relay)
   - 7.7 Servo Motor (MG996R)
   - 7.8 Human Interface (Rotary Encoder & LCD)
   - 7.9 Reserved Pins
   - 7.10 Emergency-Stop Indicator LED
8. [ESP32-CAM](#8-esp32-cam)
   - 8.1 Overview
   - 8.2 Power
   - 8.3 Programming (flashing)
   - 8.4 Data link to main controller
9. [Boot Safety & Critical Design Notes](#9-boot-safety--critical-design-notes)
10. [Bring-up & Verification Procedure](#10-bring-up--verification-procedure)
11. [Revision History](#11-revision-history)
11. [Appendix A — Master Pin Reference](#appendix-a--master-pin-reference)
12. [Appendix B — Bill of Materials Summary](#appendix-b--bill-of-materials-summary)

---

## 1. Introduction

This document presents the complete hardware wiring and electrical architecture of the Smart Decentralized Greenhouse, an academic proof-of-concept prototype intended for eventual production deployment. The system is built around an ESP32 microcontroller, powered by a regulated 5 V DC power supply, and integrates multiple analog and digital sensors, actuators, and control interfaces. All subsystems have been designed to ensure stable operation, electrical safety, and logical pin allocation for efficient firmware development.

The build is organized as nine dependency-ordered phases. Phase 1 — the subject of this document — wires every sensor and actuator to the controller and verifies that each one reads or switches correctly, with no control logic present. Establishing a clean, verified hardware baseline here removes electrical faults as a variable for every later phase (threshold control, fuzzy arbitration, RBAC, vision, ledger).

The controlling design constraints, all reflected in the pin assignments that follow, are:

- **ADC2 is unusable while Wi-Fi is active**, so every analog sensor is placed on an ADC1 channel (GPIO 32–39).
- **Strapping pins** (GPIO 0, 2, 5, 12, 15) are avoided for driven loads, with one deliberate, justified exception (GPIO 5).
- **Input-only pins** (GPIO 34, 35, 36, 39) carry only analog inputs, never outputs.
- **All actuators are binary (on/off)**, switched through an active-LOW relay module, with the 220 V grow-light circuit requiring guaranteed-off behaviour through boot. The sole exception is the MG996R servo, a PWM-driven positional actuator.

---

## 2. System Overview

Phase 1 wires the ESP32 controller to every sensor, the local interface, and every actuator, and verifies each one individually. No control logic, networking, or server software is part of this phase.

Edge power and signal flow:

```
220–230 V AC mains
   │
   ├──► S-25-5 PSU ──► 5 V rail ──► LM2596 buck ──► 3.3 V rail
   │                     │                              │
   │                     ├─ ESP32 (5V pin)              ├─ BMP280 ×2, DHT11 ×2
   │                     ├─ Relay coils (JD-VCC)        ├─ LDR ×2, soil, water
   │                     ├─ LCD, MQ135 heater           ├─ encoder, relay logic
   │                     ├─ MG996R servo (V+)           └─ level-converter LV
   │                     └─ DC loads via relay contacts
   │
   └──► Grow light (220 V), switched by relay CH7 contacts (mains-isolated)
```

The system also includes the **ESP32-CAM**, a separate camera node that runs its own firmware and joins WiFi independently. It has **no data connection to the ESP32-WROOM-32E** — no shared GPIO or signal lines — but it **is powered from the same S-25-5 5 V rail** (see §5). Its vision function is outside the scope of this phase's wiring and will be detailed separately.

---

## 3. Hardware Components & Specifications

### 3.1 Master inventory

| No | Component | Qty | Power rail | Signal type | Function | Key notes |
|----|---|-----|---|---|---|---|
| 1 | ESP32-WROOM-32E | 1 | 5 V → onboard 3.3 V reg | — (host) | Main edge controller | WiFi/BT; ADC2 unusable with WiFi |
| 2 | ESP32-CAM | 1 | 5 V (shared) | — | Camera node (separate) | No data link to main ESP32; brownout-sensitive — decouple near 5 V pin. **Sensor is OV7670-class, not the labelled OV2640** (§8.1) |
| 3 | BMP280 (RobotDyn 7-pin) | 2 | 3.3 V | I2C | Inner/outer temperature + pressure | Addr 0x76 / 0x77; **no humidity** |
| 4 | DHT11 (3-pin module) | 2 | 3.3 V | Digital 1-wire | Inner/outer relative humidity | ±5 % RH, integer output (known weak) |
| 5 | MQ135 gas sensor | 1 | **5 V** | Analog (5 V) | Air-quality / gas | Heater needs 5 V; **divider required**; 24–48 h burn-in |
| 6 | LDR module (KY-018) | 2 | 3.3 V | Analog | Inner/outer light level | Onboard divider resistor |
| 7 | Soil moisture (FC-28 + LM393) | 1 | 3.3 V | Analog (AO) | Substrate moisture | Resistive probe — corrodes under constant bias |
| 8 | Water-level sensor | 1 | 3.3 V | Analog | Reservoir level | Resistive trace; corrodes |
| 9 | 16×2 LCD (I2C backpack) | 1 | **5 V** | I2C | Local status display | PCF8574, addr 0x27/0x3F; via level converter |
| 10 | Bidirectional logic level converter | 1 | 3.3 V + 5 V | — | I2C voltage bridge for LCD | MOSFET (BSS138) type |
| 11 | Rotary encoder (EC11/KY-040) | 1 | 3.3 V | Digital | Local UI input | Needs pull-ups (internal used) |
| 12 | 8-channel relay module | 1 | 5 V coils / 3.3 V logic | Digital (active-LOW) | Actuator switching | SONGLE SRD-05VDC; JD-VCC jumper |
| 13 | MG996R servo | 1 | **5 V** | PWM (50 Hz) | Positional actuator | High-torque; stall ~2.5 A; only PWM load |
| 14 | Emergency-stop LED + 220 Ω | 1 | 3.3 V (GPIO) | Digital out | Local halt indicator | On GPIO 2; lit while the edge's NVS e-stop flag is set (§7.10) |
| 14 | DC fans (5 V) | 3 | 5 V (switched) | — (load) | Cooling + humidity exhaust | Staged ventilation (0–3 fans) |
| 15 | DC pump | 1 | 5 V (switched) | — (load) | Irrigation | |
| 16 | Ultrasonic humidifier | 1 | 5 V (switched) | — (load) | Humidity addition | Driver inrush — measure draw |
| 17 | LED string ("Normal Lights") | 1 | 5 V (switched) | — (load) | Inner lighting | |
| 18 | LED grow light | 1 | **220 V** (switched) | — (load) | Photoperiod lighting | Non-dimmable; mains-isolated |
| 19 | S-25-5 PSU | 1 | 220 V in / 5 V out | — | Primary 5 V supply | 25 W, 5 A |
| 20 | LM2596 / HW-411 buck | 1 | 5 V in / 3.3 V out | — | 3.3 V rail generator | Adjustable; set to 3.30 V |
| 21 | Resistors (2.2 kΩ, 3.3 kΩ, 10 kΩ ×7) | 9 | — | — | Passives | To be detailed later (see §7.3 & §7.6) |
| 22 | Electrolytic cap 470–1000 µF | 1 | — | — | Servo bulk decoupling | Across servo V+/GND |

### 3.2 Extended component notes

**ESP32-WROOM-32E.** Dual-core Xtensa LX6 @ 240 MHz, 2.4 GHz WiFi + BT, 3.3 V logic. Powered on the bench via USB (5 V → onboard AMS1117 → 3.3 V); for standalone operation the 5 V rail feeds the 5 V pin. Two ADC blocks exist, but **ADC2 shares hardware with the WiFi radio** and returns garbage once WiFi is up — hence the ADC1-only rule for all analog sensors.

**ESP32-CAM.** A separate camera-equipped microcontroller that runs its own firmware and joins WiFi independently. It has **no data connection** to the ESP32-WROOM-32E (no shared GPIO or signal lines) but is **powered from the shared S-25-5 5 V rail** — feed its **5 V pin** (the board regulates to 3.3 V internally). It is **brownout-sensitive**, so it needs a short, solid 5 V feed and its own decoupling capacitor near the 5 V pin; the rail's transients (servo stall, pump inrush) can otherwise reset it. Its vision function is out of scope for this phase and will be detailed separately.

**BMP280 (7-pin RobotDyn variant).** Exposes `5V · 3V3 · GND · SCK · SDO · SDI · CS` and supports both I2C and SPI. For I2C it requires two deliberate pin states: **CS tied HIGH** selects I2C mode, and **SDO selects the address** (GND → 0x76, 3.3 V → 0x77) — exactly how the two sensors are differentiated on a shared bus. Measures pressure 300–1100 hPa and temperature −40 to +85 °C; deliberately provides **no humidity**.

**DHT11.** Humidity 20–90 % RH at ±5 %, integer resolution, ≥1 s between reads. The 3-pin module carries an onboard pull-up, so no external resistor is needed. Powered at 3.3 V so its open-drain data line idles at an ESP32-safe level.

**MQ135.** Tin-dioxide gas sensor; its internal **heater requires 5 V**, so it cannot run at 3.3 V. The analog output (AO) can swing to nearly the 5 V rail, so it passes through a divider before reaching the ADC (§7.3). Requires **24–48 h burn-in** for stable readings. The 5 V digital output (DO) is **left unconnected**.

**LDR / soil / water modules.** All three are breakout modules with onboard signal conditioning that output a 0-to-VCC analog voltage. Powered at **3.3 V**, their outputs already land within the ADC range, so **none of them needs an external divider** — the MQ135 is the only analog part that does. The soil (resistive FC-28) and water-level (resistive trace) probes corrode under continuous DC bias and should not be left energised for long periods.

**16×2 LCD + level converter.** The HD44780 + PCF8574 backpack wants **5 V** for readable contrast; at 5 V its onboard pull-ups drive SDA/SCL to 5 V, which the ESP32 is **not** 5 V-tolerant for. The bidirectional level converter bridges only the LCD's two I2C lines between the 3.3 V and 5 V domains. The BMP280s are native 3.3 V and connect directly to the bus — they do **not** pass through the converter.

**8-channel relay module.** Opto-isolated, **active-LOW** (GPIO LOW = relay ON). SONGLE SRD-05VDC-SL-C relays, contacts rated ~10 A @ 250 VAC / 30 VDC. The board carries a removable **VCC ↔ JD-VCC jumper**: removing it lets the coils run from 5 V (JD-VCC) while the opto-input logic side runs from 3.3 V (VCC), so a 3.3 V GPIO HIGH fully releases the relay.

**MG996R servo.** High-torque metal-gear positional servo, 4.8–7.2 V, controlled by a 50 Hz PWM signal (≈ 500–2500 µs pulse → 0–180°). Idle draw is small, but **stall current can reach ~2.5 A**, so it is treated as a transient high-current load on the 5 V rail and given a bulk capacitor (§7.7). The 3.3 V PWM signal from the ESP32 is normally sufficient (logic threshold ~2.5 V). It is the **only** PWM-driven actuator; all others are binary relay loads.

**Power supplies.** The **S-25-5** converts mains to 5 V at up to 5 A. The **LM2596** buck steps 5 V down to a regulated **3.30 V** (~1.7 V headroom, adequate). Set and verify the LM2596 output with a multimeter **before** connecting any 3.3 V device.

---

## 4. Electrical Wiring Color Convention

A consistent color code makes the harness self-documenting and reduces miswiring. This convention covers the DC / logic side; AC mains conductors are excluded by design (see notes).

| Color | Net | Voltage level |
|---|---|---|
| 🔴 Red | +5 V | 5 V DC |
| 🟠 Orange | +3.3 V | 3.3 V DC |
| ⚫ Black | GND | — |
| 🟡 Yellow | SDA | 3.3 V logic |
| 🔵 Blue | SCL | 3.3 V logic |
| 🟢 Green | Analog signal | 0–3.3 V |
| ⚪ White | Digital signal | 3.3 V logic |
| 🟣 Purple | PWM / control output | 3.3 V logic |
| 🟤 Brown | Configuration | — |

**Notes**

- **AC mains wiring is intentionally excluded from this color convention.** The Live / Neutral / Earth conductors are distinguished by their heavier cable gauge and physical separation, not by color, so no DC/mains color collision applies. (Mains isolation requirements are covered in §9.)
- **Green has one exception:** the MQ135 signal upstream of its divider carries up to 5 V; it only becomes 0–3 V after the 2.2 kΩ/3.3 kΩ divider (§7.3). The 0–3.3 V label describes the wire at the ESP32 pin, not at the sensor.
- **Purple is the control pulse only:** the MG996R servo's power is a separate red 5 V wire; the purple wire carries just the 3.3 V PWM signal.

---

## 5. Power Supply Architecture

### 5.1 Distribution chain

```
220–230 V AC ──► S-25-5 PSU ──► 5 V RAIL ──► LM2596 buck ──► 3.3 V RAIL
                                   │
                                   └─ (also feeds 5 V consumers directly)
```

| Stage | Input | Output | Capacity |
|---|---|---|---|
| S-25-5 PSU | 220–230 V AC | +5 V / GND | 5 A (25 W) |
| LM2596 buck | 5 V | +3.30 V / GND | ~2–3 A (set by module) |

### 5.2 Rail allocation

**5 V rail** powers: ESP32 5 V pin (standalone only) · relay **JD-VCC** (coils) · LCD VCC · MQ135 VCC · **MG996R servo (V+)** · **ESP32-CAM (5 V pin)** · all switched DC loads (3 fans, pump, humidifier, LED string) through the relay **contacts**.

**3.3 V rail** powers: both BMP280 · both DHT11 · both LDR · soil module · water sensor · rotary encoder · relay **logic VCC** (opto-input side) · level-converter **LV** side.

**220 V mains** feeds: the S-25-5 input · the grow light (through CH7 relay contacts, isolated).

**ESP32-CAM** shares the 5 V rail via its 5 V pin and is included in the current budget below. Because it is brownout-sensitive, give it a dedicated decoupling capacitor close to the pin.

### 5.3 Current budget (estimates — verify by measurement)

| Rail | Consumer | Approx. current |
|---|---|---|
| 5 V | ESP32 (standalone, WiFi peak) | ~250 mA |
| 5 V | ESP32-CAM (WiFi + camera active) | ~0.2–0.3 A (brief higher spikes) |
| 5 V | Relay coils (7 × ~80 mA, all on) | ~560 mA |
| 5 V | MQ135 heater | ~150 mA |
| 5 V | LCD (+ backlight) | ~25 mA |
| 5 V | LM2596 input (to supply 3.3 V rail) | ~200 mA |
| 5 V | **MG996R servo (moving / stall)** | **~0.7 A / up to 2.5 A** |
| 5 V | 3 DC fans | ~450 mA |
| 5 V | DC pump | ~300–500 mA |
| 5 V | Ultrasonic humidifier | ~300 mA – 1 A |
| 5 V | LED string | ~200–500 mA |
| **5 V** | **Worst-case total** | **approaches / can exceed 5 A on servo stall** |
| 3.3 V | All sensors + encoder | ~50 mA |
| 3.3 V | Relay opto inputs (7 × ~5 mA) | ~35 mA |
| **3.3 V** | **Total** | **~85–100 mA** |

The simultaneous high-current case — servo motion plus pump, humidifier, and fans — is the stress point. Measure it, fit the bulk capacitor at the servo (§7.7), and avoid commanding all high-current loads at the same instant. The MG996R's stall current alone can momentarily approach half the supply's rating.

> The "0.08 mA" fan figure on the relay-board sketch is a typo — real 5 V fans draw ~80–200 mA.

### 5.4 Powering the ESP32 — bench vs standalone

- **Bench / bring-up:** power the ESP32 from **USB only** (it supplies 5 V for the Serial monitor). Do not also feed the 5 V rail to the 5 V pin simultaneously unless your board's input diode is confirmed.
- **Standalone:** connect the 5 V rail to the ESP32 **5 V pin**.
- **Never** back-feed the **3V3 pin** from the LM2596 rail — it fights the onboard regulator.

---

## 6. Grounding Topology

A single **common ground** ties together: S-25-5 GND, LM2596 input/output GND, ESP32 GND, relay logic GND, the level-converter GND (both sides), the servo GND, and every module GND. Route grounds back toward a single node (star topology) rather than daisy-chaining through high-current paths, so actuator and servo switching currents do not corrupt sensor reference voltages.

**The one exception:** the relay's **output contacts** for the grow light carry 220 V and are galvanically separate dry contacts. That mains side never connects to logic ground.

---

## 7. ESP32-WROOM-32E — Pin Architecture & Wiring

### 7.1 Pin reference (general)

| Pin Type | Pins | Description |
|---|---|---|
| Power Supply | 3V3, GND | 3V3 powers the module (up to ~500 mA peak during Wi-Fi transmission); GND is the common ground return. |
| Enable / Reset | EN (CHIP_PU) | High (> 0.75×VDD) enables the chip; Low (< 0.25×VDD) forces a hardware reset. Must be held high for normal operation. |
| Input-Only | GPIO 34, 35, 36 (SENSOR_VP), 39 (SENSOR_VN) | Input-only pins; also ADC1 channels. Cannot drive outputs and have no software-selectable internal pull-up/pull-down. |
| General-Purpose I/O | GPIO 4, 13, 14, 16, 17, 18, 19, 21, 22, 23, 25, 26, 27, 32, 33 | Bidirectional digital I/O; support PWM, and (pin-dependent) ADC, DAC, touch, SPI, I²C, UART. |
| I²C | GPIO 21 (SDA), 22 (SCL) | Default two-wire serial bus for I²C peripherals. |
| Strapping | GPIO 0, 2, 5, 12 (MTDI), 15 (MTDO) | Sampled at reset to set boot mode and flash voltage. Any pull-up/pull-down must respect the required boot level. |
| UART0 | GPIO 1 (TX0), 3 (RX0) | Primary serial port for flashing, debugging, and terminal logging via the USB-to-UART bridge. |
| Flash-Reserved | GPIO 6, 7, 8, 9, 10, 11 | Hard-wired to the module's internal SPI flash. Must not be used or connected externally. |

**General hardware rules**

- **Logic level:** all GPIO are 3.3 V; applying 5 V damages the chip.
- **ADC2 vs Wi-Fi:** ADC2 pins (GPIO 0, 2, 4, 12, 13, 14, 15, 25, 26, 27) cannot be read while Wi-Fi is active. Use ADC1 (GPIO 32–39) for continuous analog reads.
- **Boot-mode pins:** at reset GPIO 0 and 15 must be high, GPIO 12 must be low, and GPIO 2 must be low or floating. Nothing wired to them may fight those levels, or the board will not boot.

### 7.2 This project's pin use

- **ADC1 fully used for analog:** GPIO 32, 34, 35, 36, 39 carry the analog sensors (MQ135, soil, water, LDR ×2) — a direct consequence of the ADC2-with-Wi-Fi restriction above.
- **GPIO 33 borrowed as a digital input:** although it is an ADC1 pin, here it is the rotary-encoder switch (SW) — a digital input, not analog.
- **Digital-input group:** encoder CLK/DT/SW on GPIO 13/14/33 and DHT11 ×2 on GPIO 26/27, all using internal pull-ups.
- **Output group:** relay channels IN1–IN7 on GPIO 4, 5, 16, 17, 18, 19, 23, the MG996R servo PWM on GPIO 25, and the emergency-stop indicator LED on GPIO 2.
- **Strapping-pin exceptions — GPIO 5 and GPIO 2:** GPIO 5 is a relay output, safe because it idles high (relay off) and its boot glitch only briefly affects a fan. GPIO 2 drives the e-stop LED through 220 Ω to GND — the harmless strapping case, since a resistor to ground cannot pull the pin into a wrong boot level and a boot-time blip on an indicator LED has no consequence. GPIO 0, 12, 15 are left unused. These are the two deliberate exceptions to the general "avoid strapping pins" rule (§9).
- **Relay boot-safety ties to the boot-mode rule:** every relay line gets a 10 kΩ pull-up to 3.3 V and is driven high first in firmware — pull-ups on driven pins are fine here precisely because they respect the required boot levels (see §9).
- **I²C bus is shared:** GPIO 21/22 carry both BMP280s (3.3 V side) and the LCD (5 V side, via the level converter).

The complete pin-by-pin assignment is in [Appendix A](#appendix-a--master-pin-reference).

> These assignments belong to the main ESP32-WROOM-32E. The ESP32-CAM is a separate node with its own pins and is not part of this pin map.

---

The following subsections cover everything wired to the main ESP32-WROOM-32E. In every table: connect the module's power pin to the indicated rail, its ground pin to common GND, and its signal pin to the listed ESP32 GPIO.

### 7.3 Analog Sensors

All analog sensors sit on **ADC1**. The four input-only pins (34/35/36/39) carry the passive modules; GPIO 32 carries the MQ135. **Only the MQ135 needs a divider.**

| Sensor | Power | GND | Signal → ESP32 | Extra |
|---|---|---|---|---|
| LDR inner (KY-018) | 3.3 V | GND | S → **GPIO 36** | onboard divider |
| LDR outer (KY-018) | 3.3 V | GND | S → **GPIO 39** | onboard divider |
| Soil moisture (FC-28) | 3.3 V | GND | AO → **GPIO 34** | DO unconnected |
| Water level | 3.3 V | GND | S → **GPIO 35** | — |
| MQ135 | **5 V** | GND | AO → divider → **GPIO 32** | DO unconnected |

**MQ135 voltage divider:**

```
MQ135 AO ──[ R1 = 2.2 kΩ ]──┬── GPIO 32
                            │
                       [ R2 = 3.3 kΩ ]
                            │
                           GND
```

`V_adc = V_ao × R2 / (R1 + R2) = V_ao × 3.3 / 5.5 = V_ao × 0.60`

At a worst-case 5.0 V AO this yields **3.0 V** at the pin — safely under the ADC's nonlinear ceiling — with a source impedance of `R1 ∥ R2 ≈ 1.32 kΩ`. Firmware reconstructs AO by multiplying the measured pin voltage by 5.5 / 3.3.

**ADC configuration:** `analogReadResolution(12)` (0–4095), `ADC_11db` attenuation (~0–3.1 V usable).

### 7.4 Digital Sensors

| Sensor | Power | GND | Data → ESP32 |
|---|---|---|---|
| DHT11 inner | 3.3 V | GND | **GPIO 26** |
| DHT11 outer | 3.3 V | GND | **GPIO 27** |

> Module pin rule: on these 3-pin boards the **middle pin is always VCC**; the end pins are signal and GND. Match the silkscreen, not the wire color.

### 7.5 I2C Bus

One bus (`GPIO 21 = SDA`, `GPIO 22 = SCL`) carries **both BMP280s and the LCD**, split into two voltage domains by the level converter.

| Domain | Devices | Connection |
|---|---|---|
| LV (3.3 V) | ESP32 + both BMP280 | direct to GPIO 21/22 + converter LV channels |
| HV (5 V) | LCD only | converter HV channels |

**BMP280 ×2 wiring** (the two differ only on SDO):

| Module pin | Inner (0x76) | Outer (0x77) |
|---|---|---|
| 3V3 | 3.3 V | 3.3 V |
| 5V | leave open | leave open |
| GND | GND | GND |
| SCK | GPIO 22 (SCL) | GPIO 22 (SCL) |
| SDI | GPIO 21 (SDA) | GPIO 21 (SDA) |
| **SDO** | **→ GND** (sets 0x76) | **→ 3.3 V** (sets 0x77) |
| **CS** | **→ 3.3 V** (I2C mode) | **→ 3.3 V** (I2C mode) |

**Level converter & LCD wiring:**

| Converter pin | Connects to |
|---|---|
| LV | 3.3 V |
| HV | 5 V |
| GND (both) | common GND |
| LV1 ↔ HV1 | LV1 → GPIO 21 (with BMP280s) · HV1 → LCD SDA |
| LV2 ↔ HV2 | LV2 → GPIO 22 (with BMP280s) · HV2 → LCD SCL |
| (LCD) VCC / GND | 5 V / GND |

**Pull-ups:** the BMP280 boards carry onboard I2C pull-ups (the `103` = 10 kΩ resistors); two in parallel is fine. No external pull-ups required.

**Expected addresses on the bus:** `0x76`, `0x77`, and the LCD at `0x27` (or `0x3F`).

### 7.6 Actuators & Outputs (Relay)

The 8-channel **active-LOW** relay module switches the binary loads. Seven channels are used; IN8 is free.

**Logic / coil side**

| Relay pin | Connects to |
|---|---|
| GND | common GND |
| VCC (logic) | **3.3 V** |
| JD-VCC (coils) | **5 V** |
| VCC ↔ JD-VCC jumper | **REMOVED** |
| each IN line | + a **10 kΩ pull-up to 3.3 V** (boot safety) |

**Control mapping** (pin order matches the relay-board diagram; physical top-to-bottom on the ESP32 right header for a clean ribbon):

| IN | ESP32 | Load | Contact wiring (COM / NO) |
|---|---|---|---|
| IN1 | GPIO 19 | Pump | COM ← 5 V · NO → Pump(+) · Pump(−) → GND |
| IN2 | GPIO 18 | S-Fan | COM ← 5 V · NO → Fan(+) · (−) → GND |
| IN3 | **GPIO 5** | Internal Fan | COM ← 5 V · NO → Fan(+) · (−) → GND |
| IN4 | GPIO 17 | N-Fan | COM ← 5 V · NO → Fan(+) · (−) → GND |
| IN5 | GPIO 16 | Ultrasonic humidifier | COM ← 5 V · NO → Hmdfr(+) · (−) → GND |
| IN6 | GPIO 4 | Normal Lights (LED string) | COM ← 5 V · NO → LED(+) · (−) → GND |
| IN7 | GPIO 23 | **Grow light (220 V)** | COM ← **mains L** · NO → light L · light N → **mains N** |

> **GPIO 5** is a strapping pin used deliberately for the Internal Fan — see §9 for the justification. It is never used for the grow light.

### 7.7 Servo Motor (MG996R)

The MG996R is the only PWM-controlled actuator in the build. It is driven by a 50 Hz signal on a single pin; power and ground come from the 5 V rail and common ground.

| Servo wire | Connects to | Note |
|---|---|---|
| Brown (GND) | common GND | |
| Red (V+) | 5 V rail | 4.8–7.2 V; high transient/stall current |
| Orange (signal) | **GPIO 25** | 50 Hz PWM (LEDC / ESP32Servo) |

Configuration notes:

- Place a **bulk capacitor (470–1000 µF)** across the servo V+/GND, physically close to the servo, to absorb inrush and protect the shared 5 V rail.
- **Never** power the servo from the ESP32 3V3 pin.
- The 3.3 V PWM signal from GPIO 25 is normally sufficient (servo logic threshold ~2.5 V); if positioning is jittery, insert a 3.3 → 5 V level shift on the signal line.
- GPIO 25 is full-GPIO and LEDC-PWM capable; it is the only output pin used for PWM.
- On boot the firmware drives the servo to a known neutral angle (90°). Set this to your mechanism's safe rest position.

### 7.8 Human Interface (Rotary Encoder & LCD)

**Rotary encoder** — uses the ESP32 internal pull-ups (no external resistors). Must be on full-GPIO pins (not the input-only 34/35/36/39).

| Encoder pin | Power/GND | → ESP32 |
|---|---|---|
| + (VCC) | 3.3 V | — |
| GND | GND | — |
| CLK | — | **GPIO 13** (INPUT_PULLUP) |
| DT | — | **GPIO 14** (INPUT_PULLUP) |
| SW | — | **GPIO 33** (INPUT_PULLUP) |

**LCD** — see §7.5 (an I2C device on the 5 V side of the level converter).

### 7.9 Reserved Pins

| Pin(s) | Status | Reason |
|---|---|---|
| GPIO 6–11 | **Unusable** | SPI flash |
| GPIO 1, 3 | **Reserved** | UART0 — USB serial / programming |
| GPIO 0, 12, 15 | **Avoided** | Strapping pins (boot interference) |
| GPIO 2 | **Used (justified)** | Strapping pin; LED to GND is the harmless case (§7.10, §9) |
| GPIO 5 | **Used (justified)** | Strapping pin; safe for a fan load (§9) |
| 3V3 pin | **Do not drive** | Onboard-regulator output |

All other usable GPIOs are assigned; no free full-GPIO pins remain after the servo on GPIO 25 and the LED on GPIO 2.

---

### 7.10 Emergency-Stop Indicator LED

A single LED with a **220 Ω series resistor to GND on GPIO 2**, lit whenever the emergency stop is active and off otherwise. Added in v1.8 as the one physical change from v1.7.

| Part | Connects to | Note |
|---|---|---|
| LED anode (+, longer leg) | **GPIO 2** | 3.3 V logic drives it directly (~5 mA at 220 Ω) |
| LED cathode (−) | 220 Ω → common GND | Any standard 3 mm/5 mm LED; red preferred for "halted" |

**What drives it.** The edge's own NVS-persisted e-stop flag — **no server involvement**. The indicator therefore stays truthful when the network is down, the server is compromised, or the dashboard is wrong: a halted greenhouse looks halted to anyone standing in front of it regardless of what any remote system claims. This is a small, concrete reinforcement of the edge-autonomy pillar.

**Boot behaviour.** On boot the firmware reads the persisted flag and drives the LED **before anything else runs** — the same discipline as driving the relay pins HIGH first in `setup()`. If the greenhouse restarts while stopped, the light is on immediately.

**Why GPIO 2 is safe here.** GPIO 2 is a strapping pin (it must be low or floating for the download-mode strap to work), but an LED through a resistor to ground is precisely the harmless case: it cannot pull the pin high at reset, and a brief output blip from the ROM bootloader does nothing worse than flicker an indicator. This is the same class of reasoning as the GPIO 5 relay justification in §9, with a lower-stakes load. Note that many ESP32 dev boards already carry an onboard LED on GPIO 2 for exactly this reason.

**Honest limit.** The LED proves the *flag* is set. It cannot prove the actuators are actually off — a firmware bug could light the LED while a relay stays energised. It is an **indicator, not an interlock**. The interlock is the relay drive logic; the LED reports what the firmware believes.

**Buzzer considered and rejected.** An audible alarm that cannot be silenced gets muted, taped over, or disconnected within a day; a timed buzzer adds a non-blocking timer to the one code path where blocking is least acceptable. If wanted later, it is an active buzzer through a transistor as its own small task, never bundled into the control firmware's critical path.

**No contract change, no server change.** The LED is entirely internal to the edge.

---

## 8. ESP32-CAM

The ESP32-CAM is the system's **second controller** — a camera node for the vision layer. In this phase it is present and powered on the board but exchanges **no data** with the ESP32-WROOM-32E; the two share only the power rails and will coordinate over the network in a later phase. It is documented here at the same level as §7, but briefly, since its vision role is out of scope for Phase 1.

### 8.1 Overview

AI-Thinker ESP32-CAM: an ESP32 module with a camera header, a microSD slot, and an onboard 3.3 V regulator (so it accepts a 5 V supply). **The board is sold as carrying an OV2640; the unit in this build does not.** Phase 06 bring-up read sensor PID `0x2145` — an OV7670-class sensor with **no hardware JPEG encoder**. Frames are captured raw (RGB565) and compressed in software on the device (~7 KB per frame, ~100 ms). This is recorded in `Phase_06_Vision/PHASE_06_RECORD.md` §2; it changes nothing electrically but must not be misstated anywhere the hardware is listed. It runs its own firmware and joins Wi-Fi independently. It has **no USB port** — it is flashed through an external USB-to-TTL (FTDI) adapter (§8.3). None of its pins connect to the main controller.

### 8.2 Power

| CAM pin | Connects to | Note |
|---|---|---|
| 5V | 5 V rail (S-25-5) | preferred input; onboard regulator produces 3.3 V |
| GND | common GND | shared reference |

The ESP32-CAM is **brownout-sensitive**: give it a short, solid 5 V feed and a decoupling capacitor (≥ 100 µF, 470–1000 µF preferred) close to its 5 V pin. Transients on the shared rail (servo stall, pump inrush) can otherwise reset it. Never power it from the WROOM-32E's 3V3 pin.

**Verified in Phase 06:** the brownout is real and reproducible. Powered from a USB-TTL adapter's 5 V pin, the board reset on the second HTTPS upload (`E BOD: Brownout detector was triggered`) — capture, software JPEG encode, TLS handshake and WiFi transmit coincide within a few hundred milliseconds. Moving the 5 V feed to the S-25-5 rail resolved it. See §8.3.

### 8.3 Programming (flashing)

The board has no USB, so flashing uses a temporary USB-to-TTL adapter — a bench connection only, not part of the runtime wiring:

| CAM pin | Connects to | Note |
|---|---|---|
| 5V | **S-25-5 5 V rail** | **Not the FTDI's 5 V pin** — see below |
| GND | common GND **and** FTDI GND | both; the FTDI ground is the serial reference |
| U0T (GPIO 1) | FTDI RX | 3.3 V logic |
| U0R (GPIO 3) | FTDI TX | 3.3 V logic |
| GPIO 0 | GND — **only while flashing** | remove and reset to run |
| FTDI 5V | **not connected** | never two supplies on one rail |

**Why not the FTDI's 5 V (learned in Phase 06).** Flashing over FTDI power *works*; running the upload path over it does not — the board browns out under the combined capture + TLS + WiFi-TX load. Two other faults were traced to bench power in the same session: a 3.3 V feed instead of 5 V produced flash writes that reported success and verified against the same wrong MD5 every time (`Flash memory erased successfully in 0.0 seconds` was the tell); and leaving the FTDI ground disconnected once power moved to the rail produced unreadable serial. Power from the rail, share ground with the FTDI, leave the FTDI's 5 V open.

Tie GPIO 0 to GND to enter download mode, upload the firmware, then remove that link and reset for normal operation.

### 8.4 Data link to main controller

None in this phase. The ESP32-CAM and the ESP32-WROOM-32E are not wired together — no shared GPIO, I2C, or UART — and no pin on the main controller is allocated to the camera (Appendix A). Coordination between the two runs over the network and belongs to a later phase.

---

## 9. Boot Safety & Critical Design Notes

**Relay boot safety.** Every ESP32 GPIO is high-impedance from reset until firmware runs. On an active-LOW board a floating input can drift LOW = relay ON. Three layers prevent this, mattering most for the 220 V grow light:

1. **10 kΩ pull-up** from each IN line to the 3.3 V logic VCC — holds IN HIGH (OFF) during the float window.
2. **Firmware drives every relay pin OUTPUT + HIGH as the first action in `setup()`**, before Serial, I2C, or WiFi. **Second action: read the NVS e-stop flag and drive the GPIO 2 LED** (§7.10). Everything else follows.
3. Relays are kept off strapping pins (except GPIO 5, justified below).

**GPIO 5 justification.** GPIO 5 is a strapping pin (SDIO slave timing), but that strap is irrelevant when booting from SPI flash, and it has an internal pull-up so it idles HIGH = relay OFF. Its only quirk is a possible brief output blip from the ROM bootloader before `setup()` runs. On the **Internal Fan**, a sub-second twitch at power-on is harmless — which is precisely why a fan, not the grow light, is assigned here.

**GPIO 2 justification.** GPIO 2 is a strapping pin, but the e-stop LED is wired through 220 Ω to ground — the one load that cannot interfere with a strap: it never pulls the pin high, and the ROM bootloader's brief blip on an indicator is invisible in practice. It is the lowest-stakes pin use in the build and is placed on the strapping pin precisely so that a full-GPIO pin is not spent on it.

**Servo at boot.** The firmware sets the MG996R to a known neutral angle (90°) at startup. The 5 V rail must tolerate the servo's transient current — the bulk capacitor at the servo (§7.7) is mandatory, not optional.

**Mains isolation.** The grow-light relay's COM/NO contacts carry 220 V and are isolated dry contacts. That side never touches logic ground; keep its wiring physically separated and strain-relieved.

**5 V budget.** Verify worst-case 5 V current (§5.3) before running all actuators together; servo stall is the dominant transient.

**Sensor corrosion.** The FC-28 and water-level probes corrode under continuous DC and should not be left energised for long periods.

---

## 10. Bring-up & Verification Procedure

The test sketch (`greenhouse_phase1_bringup.ino`) reads every sensor, sweeps the servo, and toggles each relay over Serial, with no control logic. Recommended order — each step isolates a class of fault before the next:

1. **Power rails first.** Set the LM2596 to 3.30 V (multimeter, no devices attached). Confirm 5 V and 3.3 V rails and common ground.
1a. **E-stop LED.** Wire the LED + 220 Ω on GPIO 2. Command `e` toggles it. Power-cycle three times: it must come up in the state the flag was left in, and must not flicker on when the flag is clear.
2. **I2C subsystem.** Wire the two BMP280s and the LCD (via level converter). Flash the sketch; the startup **I2C scan** must report `0x76`, `0x77`, and the LCD address. A missing BMP280 points directly at its SDO/CS wiring.
3. **Analog modules.** Add the LDRs, soil, water, and MQ135 (with divider). Confirm raw values respond. The MQ135 needs burn-in before its reading settles.
4. **Digital inputs.** Add the DHT11s and the encoder; confirm humidity reads and the encoder position/button track.
5. **Relays — logic only.** Wire the IN ribbon and coil/logic power (jumper removed). Toggle channels `1`–`7` over Serial and confirm each click. **Keep the grow-light circuit de-energised.**
6. **Servo.** Wire the MG996R (with bulk capacitor). Command the sweep and confirm smooth full-range motion with no rail brownout (the LCD/sensors should not glitch during motion).
7. **Mains last.** Only after CH7 has been verified silent through several resets, wire the 220 V grow light and confirm switching via command `7`.

Serial: 115200 baud. Commands: `1`–`7` toggle a relay, `v` sweep servo, `e` toggle e-stop LED, `x` all off, `s` re-scan I2C, `h` help.

---

## Appendix A — Master Pin Reference

| ESP32 pin | Direction | Connects to | Device rail |
|---|---|---|---|
| GPIO 36 (SVP) | ADC1 in | LDR inner — S | 3.3 V |
| GPIO 39 (SVN) | ADC1 in | LDR outer — S | 3.3 V |
| GPIO 34 | ADC1 in | Soil module — AO | 3.3 V |
| GPIO 35 | ADC1 in | Water sensor — S | 3.3 V |
| GPIO 32 | ADC1 in | MQ135 — AO via 2.2k/3.3k divider | 5 V |
| GPIO 21 | I2C SDA | BMP280 ×2 SDI + level-conv LV1 | 3.3 V |
| GPIO 22 | I2C SCL | BMP280 ×2 SCK + level-conv LV2 | 3.3 V |
| GPIO 26 | digital in | DHT11 inner — data | 3.3 V |
| GPIO 27 | digital in | DHT11 outer — data | 3.3 V |
| GPIO 13 | in (pull-up) | Encoder — CLK | 3.3 V |
| GPIO 14 | in (pull-up) | Encoder — DT | 3.3 V |
| GPIO 33 | in (pull-up) | Encoder — SW | 3.3 V |
| GPIO 19 | digital out | Relay IN1 — Pump | logic 3.3 V |
| GPIO 18 | digital out | Relay IN2 — S-Fan | logic 3.3 V |
| GPIO 5 | digital out | Relay IN3 — Internal Fan | logic 3.3 V (strapping) |
| GPIO 17 | digital out | Relay IN4 — N-Fan | logic 3.3 V |
| GPIO 16 | digital out | Relay IN5 — Ultrasonic humidifier | logic 3.3 V |
| GPIO 4 | digital out | Relay IN6 — Normal Lights | logic 3.3 V |
| GPIO 23 | digital out | Relay IN7 — Grow light (220 V) | logic 3.3 V |
| GPIO 25 | PWM out | MG996R servo — signal | 5 V (servo power) |
| GPIO 2 | digital out | E-stop indicator LED — anode, 220 Ω to GND | logic 3.3 V (strapping, safe) |
| 5V | power in | 5 V rail (standalone) / USB (bench) | — |
| 3V3 | — | do not drive | — |
| GND | ground | common ground node | — |

**Reserved/unusable:** GPIO 6–11 (flash), 1/3 (UART0), 0/12/15 (strapping). GPIO 2 and 5 are strapping pins used with justification (§9).

**ESP32-CAM:** separate node — no pins on the ESP32-WROOM-32E are allocated to it.

---

## Appendix B — Bill of Materials Summary

| Category | Items |
|---|---|
| Controllers | ESP32-WROOM-32E (×1), ESP32-CAM (×1, separate node — no data link, shares 5 V) |
| Sensors | BMP280 ×2, DHT11 ×2, MQ135 ×1, LDR ×2, soil FC-28 ×1, water level ×1 |
| Interface | 16×2 I2C LCD ×1, rotary encoder ×1, level converter ×1 |
| Actuation | 8-ch relay ×1, MG996R servo ×1; loads: 3× DC fan, pump, ultrasonic humidifier, LED string, 220 V grow light |
| Power | S-25-5 PSU (5 V/5 A) ×1, LM2596/HW-411 buck ×1 |
| Passives | 2.2 kΩ ×1, 3.3 kΩ ×1 (MQ135 divider); 10 kΩ ×7 (relay pull-ups); 220 Ω ×1 (e-stop LED); 470–1000 µF ×2 (servo bulk cap, ESP32-CAM decoupling) |
| Indicators | LED ×1 (e-stop, GPIO 2) |

---

*End of document — Phase 1 wiring locked.*

---

## 11. Revision History

| Version | Date | Change |
|---|---|---|
| 1.7 | 19 June 2026 | Wiring locked. Baseline for the physical build. |
| 1.8 | 6 September 2026 | **One physical addition:** emergency-stop indicator LED on GPIO 2, 220 Ω to GND (§7.10, §7.2, §7.9, §9, §10, Appendix A/B). **Two corrections from Phase 06 bring-up, no wiring change:** §8.1 — the ESP32-CAM's sensor is OV7670-class (PID `0x2145`), not the labelled OV2640, and has no hardware JPEG encoder; §8.2–8.3 — the CAM must be powered from the S-25-5 rail, not a USB-TTL adapter's 5 V pin, with the adapter's ground shared; brownout under upload load and a 3.3 V flash-verify failure were both reproduced on the bench. |

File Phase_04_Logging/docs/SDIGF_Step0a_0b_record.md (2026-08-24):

# SDIGF — Server Tier: Step 0a & 0b Record

**Project:** Smart Decentralized Greenhouse (SDIGF)
**Repo:** `github.com/soul-taker-55/smart-decentralized-greenhouse`
**Document date:** 2026-08-24
**Covers:** Step 0a (infrastructure) — COMPLETE · Step 0b (MQTT contract) — Parts 1–2 of 4

> **Purpose of this document.** It is both a decision record and the draft frozen contract.
> Where a choice was made, the reasoning is recorded alongside it, because the reasoning is
> what makes the choice reviewable later. Sections marked **OPEN** are not yet decided.

---

## 0. Where the project stands

### The nine phases

| # | Name | Tier | Status |
|---|---|---|---|
| 1 | Wiring & bring-up | Edge | ✅ complete (wiring doc v1.7) |
| 2 | Standalone edge control | Edge | not started |
| 3 | Connectivity (MQTT) | Edge | not started |
| **4** | **Data & logging** | **Server** | **current** |
| 5a | Backend & dashboard | Server | |
| 5b | MCP server & chat | Server | |
| 6 | Access control, approval & signing | Server | |
| 7 | Fuzzy arbiter *(optional — only if logs justify)* | Edge | |
| 8 | Vision *(independent, any time after Phase 3)* | Server | |
| 9 | Ledger *(last)* | Server | |

Original dependency order: 1 → 2 → 3 → 4 → 5a → 5b → 6 → 7 → 9.
**Revised server-tier order:** 4 → 5a → 6 → 9 → 5b. The ledger needs signed events from
Phase 6, whereas MCP only wraps whatever API already exists — so the hardest server piece
gets built while there is still runway.

### Server-tier prep progress

```
0a  broker + DB + auth          ██████████  complete
0b  freeze MQTT contract        █████░░░░░  Parts 1–2 of 4 done
0c  mock edge simulator         ░░░░░░░░░░
4   DB + bridge + queries       ░░░░░░░░░░
```

Steps 0a–0c sit *underneath* Phase 4. They exist only because the server tier is being built
before the edge firmware, so a frozen interface and a fake ESP32 are needed to build against.

---

## 1. Step 0a — Infrastructure (COMPLETE)

### What is running

| Service | Image | Notes |
|---|---|---|
| `sdigf-db` | `timescale/timescaledb:latest-pg16` | Postgres 16 + TimescaleDB |
| `sdigf-emqx` | `emqx/emqx:latest` | v6.2.3, broker + dashboard |

Deployed as a **single Docker Compose stack** in Dokploy, sourced from GitHub at
`Phase_04_Logging/server/docker-compose.yml`, redeploying on push.

### Endpoints

| Purpose | Address | Exposure |
|---|---|---|
| EMQX dashboard (HTTP) | `eqmx.progrex.tech` | Traefik + TLS |
| MQTT broker (TCP 1883) | server IP / DNS A record | direct, **not** through Traefik |
| Postgres | internal Docker network only | not exposed |

### Verified

- ✅ Schema applied automatically on first boot — 10 tables
- ✅ TimescaleDB extension loaded
- ✅ Broker reachable from MQTTX
- ✅ **Retained message survives client disconnect/reconnect** (confirmed by the `Retained`
  badge in MQTTX). This is the single behaviour the entire edge-reconnect design rests on.
- ✅ Authentication enabled — Built-in Database, password-based, SHA-256

### Broker accounts

| Username | Used by | Superuser |
|---|---|---|
| `sdigf-edge` | ESP32 firmware, and the Step 0c mock | No |
| `sdigf-bridge` | Phase 4 MQTT→DB bridge | No |
| `sdigf-backend` | Phase 5a REST backend | No |
| `sdigf-admin` | MQTTX / manual inspection | No |

Separate accounts are deliberate: Phase 6 ACLs attach to usernames. A single shared account
would have to be unpicked later.

### Decisions made, and why

**EMQX instead of Mosquitto.** Mosquitto is lighter (~10 MB / ~50 MB RAM vs ~200 MB / ~300 MB)
and technically sufficient for one greenhouse. EMQX was chosen for its **built-in management
dashboard** — a requirement stated by the project owner. The server has 11.7 GB RAM, so the
overhead is not material.

**TimescaleDB over InfluxDB.** One Postgres instance holds telemetry (hypertable), config
history, users, and the ledger. That means one backup, one connection string, and the ability
to JOIN telemetry against config events — which the Phase 4 conflict-frequency queries need.
InfluxDB would add a second stateful service and a second query language for no gain at this
scale.

**MQTT is not routed through Traefik.** MQTT is raw TCP; Traefik in this setup routes
HTTP/HTTPS. The dashboard gets a Dokploy domain; the broker gets a plain DNS A record to the
server IP. *(This was attempted incorrectly twice before being resolved.)*

**Ledger as tables, not a service.** An append-only table with a `prev_hash` column and a
trigger rejecting UPDATE/DELETE is the entire mechanism. A separate service adds nothing until
Phase 9 proves otherwise.

### Deployment problems encountered (recorded so they are not repeated)

| Symptom | Cause | Fix |
|---|---|---|
| `Compose file not found` | Path case/spelling mismatch against the real repo folder | Use the exact folder name: `Phase_04_Logging/server/docker-compose.yml` |
| `invalid interpolation format ... ${{project.VAR}}` | Dokploy UI syntax is invalid inside a git-stored compose file | Use standard `${VAR}` and set the value in Dokploy's Environment tab |
| `not a directory: mounting mosquitto.conf` | File absent from the repo, so Docker created an empty **directory** at that path | Ensure the file exists in git; delete the stray directory on the server before redeploying |
| `Unable to open pwfile` | Config referenced a `password_file` that was never created | Remove the reference, or create the file |
| `No such container: sdigf-db-1` | Dokploy prefixes container names | Get the real name from `docker ps` |

**Operational note:** Dokploy's *Open Terminal* attaches to a **container**, not the host.
Host-level commands (`docker ps`, `docker volume rm`, pruning) require SSH.

### Server cleanup performed

Disk went from **29 GB → 19 GB used** (64% → 40%):
- 2.7 GB of archived systemd journals vacuumed
- ~7.2 GB of unused Docker images removed (old Dokploy version, EMQX leftover, dangling layers)
- Retired projects removed: exam-generator, hospital-management, osticket

Docker log rotation was applied (`max-size 10m`, `max-file 3`) to prevent recurrence.

### ⚠ Outstanding from Step 0a

- **Broker-restart retention was never tested.** What was verified is *client* reconnect.
  Restarting the broker container and confirming a retained message survives is a different
  guarantee, and it is the one the edge design actually depends on. **Do this before Phase 3.**
- **Volume and database backups are not yet configured** (`sdigf_db_data`, `sdigf_emqx_data`).

---

## 2. ⚠ Correction: the provisional database schema

A 10-table schema was written and applied to `sdigf_db` during Step 0a. **This was premature.**

Phase 4's schema is supposed to be *derived from* the frozen MQTT contract — the field names,
types, and quality semantics all come from Step 0b. The applied tables are a reasonable
skeleton but should be treated as **provisional**. Expect column renames and type changes once
Parts 3 and 4 below are settled.

Ground-truth rule for this project: **the GitHub repository is canonical.** Uploaded files or
earlier conversation content must never override it.

---

## 3. Step 0b Part 1 — Topic tree (SIGNED OFF)

```
sdigf/v1/gh1/up/telemetry      ESP32 → server
sdigf/v1/gh1/up/actuators      ESP32 → server
sdigf/v1/gh1/up/health         ESP32 → server
sdigf/v1/gh1/up/ack            ESP32 → server
sdigf/v1/gh1/status            ESP32 → server  (last will)

sdigf/v1/gh1/down/config       server → ESP32
sdigf/v1/gh1/down/cmd          server → ESP32
```

**`v1` in the path.** When the contract changes, `v2` topics can run alongside `v1` during
migration rather than breaking every client simultaneously. Costs nothing now.

**`gh1` as a device slot.** A second greenhouse becomes `gh2` with no redesign. The bridge
subscribes with a wildcard: `sdigf/v1/+/up/telemetry`.

**`up` / `down` in the path.** Direction is visible in the topic itself, which makes Phase 6
ACLs nearly trivial: `sdigf-edge` gets publish on `up/#` and subscribe on `down/#`, nothing
else.

### QoS and retain

Governing rule: **retain state, do not retain events.**

| Topic | QoS | Retained | Reasoning |
|---|---|---|---|
| `up/telemetry` | 0 | no | A stream. Losing one reading is harmless — the next arrives shortly. QoS 1 would fill the ESP32 inflight buffer whenever the broker is slow. |
| `up/actuators` | 1 | **yes** | Current state. A freshly connected dashboard must see what is on right now. |
| `up/health` | 0 | **yes** | Current state, but not worth a retry. |
| `up/ack` | 1 | no | An event — and the one that proves what the hardware actually applied. Must not be lost. |
| `status` | 1 | **yes** | A last will must be retained, or a late subscriber never learns the edge is down. |
| `down/config` | 1 | **yes** | The reconnect design depends on this. Verified working in Step 0a. |
| `down/cmd` | 1 | no | An event with a TTL. Retaining it would re-fire on every reconnect. |

### Batched telemetry (signed off)

All sensor readings travel in **one message**, not one topic per sensor.

Rationale — nothing in the system ever wants a single sensor in isolation:
- The bridge writes every reading to one table with one timestamp.
- The dashboard renders all gauges together.
- The control loop reads temperature **and** humidity together to evaluate Conflict A. Split
  topics would require pairing messages that arrived at slightly different times — a bug
  waiting to happen.
- The ESP32 reads all sensors in one loop pass anyway; publishing separately would mean many
  packets each carrying a copy of the same timestamp.

Per-sensor topics earn their keep when different consumers care about different sensors
independently (e.g. a 400-room building). That is not this system.

**Revisit if:** a single greenhouse ever exceeds roughly 30–40 readings, at which point the
batch would strain the ESP32 MQTT buffer.

---

## 4. Step 0b Part 2 — Payload schemas (DRAFT — awaiting sign-off)

### Shared envelope

Every edge→server message carries these, so the bridge can validate uniformly.

| Field | Type | Meaning |
|---|---|---|
| `v` | int | **Schema** version — not config version. Bump when payload shape changes. |
| `ts` | int | Unix epoch seconds, device clock |
| `tsq` | string | Timestamp quality: `ntp` (synced) or `boot` (seconds since boot; wall-clock meaningless) |
| `seq` | int | Monotonic counter, resets on reboot. Lets the server detect gaps. |

**Timestamp trust.** The ESP32 has no RTC. Before NTP syncs, `ts` is not wall-clock time —
hence `tsq`. **The bridge must record both the device timestamp and its own receive time**, and
prefer server time when `tsq` is `boot`. Without this, 1970-dated rows land in the thesis
dataset.

**MQTT buffer size.** Arduino `PubSubClient` defaults to a **256-byte** buffer and fails
*silently* when exceeded — the publish simply does not happen. Telemetry below is ~480 bytes.
**Phase 3 firmware must call `setBufferSize(1024)`.** This is a required item, not advice.

---

### 4.1 `up/telemetry` — QoS 0, not retained

```json
{
  "v": 1,
  "ts": 1756036800,
  "tsq": "ntp",
  "seq": 142,
  "r": {
    "temp_in":   {"val": 24.3,   "q": "ok"},
    "temp_out":  {"val": 19.8,   "q": "ok"},
    "press_in":  {"val": 1012.4, "q": "ok"},
    "press_out": {"val": 1012.1, "q": "ok"},
    "hum_in":    {"val": 58,     "q": "ok"},
    "hum_out":   {"val": null,   "q": "fail"},
    "aq":        {"val": 142,    "q": "ok"},
    "light_in":  {"val": 812,    "q": "ok"},
    "light_out": {"val": 2140,   "q": "ok"},
    "soil":      {"val": 41,     "q": "stale"},
    "water":     {"val": 78,     "q": "ok"}
  }
}
```

| Key | Source | Type | Unit | Notes |
|---|---|---|---|---|
| `temp_in` | BMP280 @0x76 | float | °C | 1 decimal |
| `temp_out` | BMP280 @0x77 | float | °C | 1 decimal |
| `press_in` | BMP280 @0x76 | float | hPa | 1 decimal |
| `press_out` | BMP280 @0x77 | float | hPa | 1 decimal |
| `hum_in` | DHT11 GPIO26 | int | %RH | integer only — sensor limitation |
| `hum_out` | DHT11 GPIO27 | int | %RH | integer only |
| `aq` | MQ135 GPIO32 | int | raw ADC | **relative trend, not ppm** |
| `light_in` | LDR GPIO36 | int | raw ADC | 0–4095 |
| `light_out` | LDR GPIO39 | int | raw ADC | 0–4095 |
| `soil` | FC-28 GPIO34 | int | % | mapped from ADC |
| `water` | GPIO35 | int | % | mapped from ADC |

#### Quality values

| `q` | Meaning | `val` | Control loop should |
|---|---|---|---|
| `ok` | Fresh and within plausible range | number | use it |
| `stale` | Last good value, older than that sensor's max age | last known number | use with caution, or fall back |
| `fail` | Read error, or outside physical bounds | `null` | **not** use it — fail safe |
| `init` | Never successfully read since boot | `null` | not use it |

`init` is distinct from `fail` on purpose: a DHT11 needs a couple of seconds before its first
reading, and without a separate state it is impossible to distinguish "broken" from "not asked
yet." That distinction appears in the logs after every reboot.

**The null rule.** When `q` is `fail` or `init`, `val` is always `null` — never `0` or `-127`.
Sentinel values leak into averages and quietly corrupt the dataset. `null` maps directly to
SQL `NULL` and is excluded from aggregates automatically.

**Why raw ADC for light and air quality.** Neither is calibrated. `aq` is explicitly a relative
trend per the project's stated caveats; calibrating an LDR to lux would invent precision that
does not exist. Store raw, interpret during analysis — this is the defensible choice
academically.

**Design change recorded:** an earlier draft used a single `"bad": [...]` exception list to
keep payloads small. Rejected in favour of explicit per-reading quality. It costs ~260 bytes
but lets the bridge write `quality_flag` per row with no inference, and lets the Phase 4
conflict queries filter `WHERE quality_flag = 'ok'` directly. Given DHT11 is the only humidity
source and its weakness is already a stated caveat, being able to say *"N excludes intervals
where humidity was unreliable"* is worth the bytes.

---

### 4.2 `up/actuators` — QoS 1, **retained**

```json
{
  "v": 1,
  "ts": 1756036800,
  "tsq": "ntp",
  "seq": 142,
  "a": {
    "pump":         {"on": false, "src": "auto",   "for_s": 0},
    "s_fan":        {"on": true,  "src": "auto",   "for_s": 340},
    "internal_fan": {"on": true,  "src": "auto",   "for_s": 340},
    "n_fan":        {"on": false, "src": "auto",   "for_s": 0},
    "humidifier":   {"on": false, "src": "auto",   "for_s": 0},
    "lights":       {"on": true,  "src": "manual", "for_s": 120},
    "grow_light":   {"on": true,  "src": "auto",   "for_s": 7200}
  },
  "canopy": {"pos": 40, "target": 40, "moving": false, "src": "auto"},
  "vent": 2
}
```

| Field | Type | Meaning |
|---|---|---|
| `on` | bool | Logical state. **Note: this is logical, not electrical** — the relay module is active-LOW, so `on: true` means the GPIO is driven LOW. |
| `src` | string | `auto` (control loop), `manual` (server command), `safety` (envelope override) |
| `for_s` | int | Seconds in the current state. Feeds the pump max-runtime guard, relay minimum-off-time, and stuck-actuator detection. |
| `canopy.pos` | int 0–100 | Believed current position, % closed |
| `canopy.target` | int 0–100 | Commanded position |
| `canopy.moving` | bool | True during travel |
| `vent` | int 0–3 | Derived ventilation stage (count of fans running) |

**Why `src` exists.** The Phase 4 event log and the Phase 9 ledger both need to distinguish
autonomous action from human action. Recording it at the point of state change is far more
reliable than inferring it later by correlating timestamps.

**Why `vent` is published even though it is derivable.** It is the value the control policy is
written against (staged 0–3). Publishing it explicitly means the server never has to reimplement
the fan→stage mapping, so the two cannot drift apart.

**Why `canopy` sits outside the `a` block.** It is positional, not binary. Keeping it separate
prevents the server from having to special-case one key inside an otherwise uniform map.

**Position is *believed*, not measured.** The MG996R has no feedback. `pos` is what the firmware
commanded, and it may not reflect physical reality if the canopy jams. Per the hardware
constraints: command the move, wait the travel time, then **detach the signal** — never hold
position indefinitely, because a stalled MG996R draws ~2.5 A and will brown out the 5 V rail.

---

### 4.3 `up/health` — QoS 0, **retained**

```json
{
  "v": 1,
  "ts": 1756036800,
  "tsq": "ntp",
  "seq": 142,
  "up_s": 84213,
  "rssi": -67,
  "heap": 142880,
  "heap_min": 118004,
  "fw": "0.3.1",
  "cfg": {"ver": 7, "hash": "9f2c…a1", "src": "mqtt"},
  "mqtt_reconnects": 3,
  "boot_reason": "power_on"
}
```

| Field | Type | Meaning |
|---|---|---|
| `up_s` | int | Seconds since boot |
| `rssi` | int | WiFi signal, dBm |
| `heap` | int | Free heap, bytes |
| `heap_min` | int | Lowest free heap since boot — catches slow leaks a spot reading misses |
| `fw` | string | Firmware version |
| `cfg.ver` | int | Config version **currently running** |
| `cfg.hash` | string | Canonical hash currently running |
| `cfg.src` | string | `mqtt` (received from server) or `nvs` (last-known-good after a restart with no broker) |
| `mqtt_reconnects` | int | Reconnect count since boot — a rising number indicates link instability |
| `boot_reason` | string | `power_on`, `watchdog`, `panic`, `brownout`, `sw_reset` |

**`cfg.src` is load-bearing for the thesis.** It is the field that makes edge autonomy visible
and provable: when the broker is unreachable and the ESP32 restarts, this reads `nvs`, showing
the greenhouse ran correctly on last-known-good config with no server involvement.

**`boot_reason` = `brownout`** is the specific signature of a stalled canopy servo or an
ESP32-CAM inrush on the shared 5 V rail. Worth capturing rather than diagnosing blind.

---

### 4.4 `up/ack` — QoS 1, not retained

**The most important payload in the contract.** This is what proves the hardware is running
exactly what was approved — the last link in the chain of evidence.

Accepted:
```json
{
  "v": 1,
  "ts": 1756036800,
  "tsq": "ntp",
  "seq": 143,
  "ref": {"ver": 8, "hash": "3d81…c4"},
  "result": "accepted",
  "applied": {"ver": 8, "hash": "3d81…c4"},
  "reason": null
}
```

Rejected:
```json
{
  "v": 1,
  "ts": 1756036800,
  "tsq": "ntp",
  "seq": 143,
  "ref": {"ver": 8, "hash": "3d81…c4"},
  "result": "rejected",
  "applied": {"ver": 7, "hash": "9f2c…a1"},
  "reason": {
    "code": "ENVELOPE",
    "field": "pump.max_runtime_s",
    "detail": "1800 exceeds hard limit 600"
  }
}
```

| Field | Meaning |
|---|---|
| `ref` | Version and hash of the config **received** |
| `result` | `accepted` \| `rejected` |
| `applied` | Version and hash **now running**. On rejection this is the *previous* config — the edge never ends up running nothing. |
| `reason` | `null` when accepted; otherwise a structured object |

#### Rejection codes

| Code | Meaning |
|---|---|
| `ENVELOPE` | Violates a hardcoded equipment limit. **Non-negotiable regardless of how well signed.** |
| `HASH_MISMATCH` | Recomputed canonical hash ≠ the hash in the payload |
| `NOT_NEWER` | `ver` ≤ currently running version |
| `PARSE` | Malformed JSON, or missing required field |
| `SCHEMA` | Unsupported `v` (schema version) |

**Why `ref` and `applied` are separate.** They are the same on success and deliberately
different on rejection. This lets the server state, from the record alone, both *what was sent*
and *what is actually running* — without which "the hardware is running exactly what was
approved" is an unverifiable claim.

**Why rejection reasons are structured, not free text.** The dashboard needs to render them,
the ledger needs to record them, and the thesis needs to count them by category. Free-form
strings cannot be aggregated.

**`ENVELOPE` is the demo's centrepiece.** It demonstrates the second enforcement gate: the edge
rejects an unsafe config *even when correctly signed by a valid quorum*. Server RBAC and edge
safety are independent gates, and this code is where that independence becomes visible.

---

### 4.5 `status` — QoS 1, **retained** (last will)

Published by the device on connect:
```json
{"v": 1, "state": "online", "ts": 1756036800}
```

Set as the Last Will at connection time:
```json
{"v": 1, "state": "offline"}
```

**A last-will payload is fixed when the client connects and cannot contain a current
timestamp** — the broker publishes bytes chosen minutes or hours earlier. So the offline
message carries no `ts`. **The server must timestamp offline events on receipt.** Attempting to
put a device timestamp in a last will produces a message claiming the device went offline at
the moment it came *online*.

Both are retained so that any subscriber connecting later immediately learns the current state.

---

### 4.6 `down/config` — QoS 1, **retained**

```json
{
  "v": 1,
  "ts": 1756036800,
  "ver": 8,
  "hash": "3d81…c4",
  "cfg": { "…": "see Part 3 (OPEN)" }
}
```

| Field | Meaning |
|---|---|
| `ver` | Monotonically increasing config version. The edge applies only if strictly greater than what it is running. |
| `hash` | Canonical hash of `cfg` — see Part 4 (OPEN) |
| `cfg` | The control parameters themselves — see Part 3 (OPEN) |

**`hash` covers `cfg` only**, not the envelope. `ts` and `v` are transport metadata and must not
affect the signed value — otherwise re-publishing an unchanged config would produce a different
hash and break signature verification.

**Retained is essential.** A reconnecting ESP32 receives the current config immediately without
the server having to detect the reconnection and re-push. Verified working in Step 0a.

---

### 4.7 `down/cmd` — QoS 1, not retained

```json
{
  "v": 1,
  "ts": 1756036800,
  "id": "c8f21e",
  "target": "humidifier",
  "action": "on",
  "ttl_s": 300,
  "by": {"user": "farmer-01", "role": "FARMER"}
}
```

| Field | Meaning |
|---|---|
| `id` | Unique command ID. Enables idempotency and correlation with the event log. |
| `target` | Actuator key, matching `up/actuators`, or `canopy` |
| `action` | `on` \| `off` \| `set` (with `value` for canopy position) \| `release` |
| `ttl_s` | Seconds this override remains in force. **Required — no unbounded manual overrides.** |
| `by` | Actor and role. Populated in Phase 6; present in the schema from day one. |

**Manual override reconciliation** (answering the Phase 3 requirement of *who wins, for how
long, how it expires*):

1. A manual command overrides autonomous control for its `target` only.
2. It holds for `ttl_s` seconds, then **automatically expires** and control returns to `auto`.
3. `release` ends the override early.
4. **The safety envelope always wins.** A manual command that would exceed pump max-runtime is
   cut short by the envelope, and `src` becomes `safety`.
5. Overrides do **not** survive reboot. After a restart the edge resumes autonomous control on
   last-known-good config — an operator override must never silently persist across a power cut.

**Why not retained.** A retained command would re-fire on every reconnect, meaning a pump
switched on manually last week would restart itself after a power cut. Commands are events with
an expiry; state belongs on the config topic.

---

## 5. OPEN — remaining work in Step 0b

### Part 3 — Config payload structure

The actual control parameters the agriculture engineer sets. **No agronomic values are to be
invented** — the engineer supplies them; the contribution is the mechanism.

Must cover:
- temperature band + hysteresis
- humidity band + hysteresis
- soil moisture threshold
- pump max runtime and cooldown
- photoperiod schedule
- ventilation staging thresholds (levels 0–3)
- canopy policy: allowed-for-cooling, max shade minutes/day, only-above-threshold
- **conflict arbiter policy for Conflict A** (fans vs. humidifier — hot AND dry together)
- **conflict arbiter policy for Conflict B** (canopy vs. photoperiod)

### Part 4 — Canonical serialization spec

The highest-risk item in the whole project. This hash is computed independently by **four**
implementations:

| Implementation | Purpose |
|---|---|
| Browser (WebCrypto) | signs it |
| Server (Node.js) | verifies and stores it |
| Ledger | records it |
| ESP32 | confirms what it received |

If any one drifts, signatures fail in ways that are very hard to diagnose.

Must define precisely: key ordering · whitespace · number formatting · float precision ·
encoding · null handling — **plus a fixed test vector** (a sample config and its expected hash)
that every implementation can be checked against.

### Also outstanding

- Broker-restart retention test (carried over from Step 0a)
- Backups for `sdigf_db_data` and `sdigf_emqx_data`
- MQTTX test payloads for every topic, so the contract can be exercised by hand before either
  tier is written

---

## 6. Working agreements

- **Ground truth:** the GitHub repository. Uploaded files and prior conversation never override it.
- Step-by-step with sign-off before code.
- Simple, direct language.
- Arabic documentation is maintained alongside English. The canonical Arabic term is
  **البيوت الزراعية الذكية**; **دفيئة** is never used.
- Thesis chapter structure maps to phases, which map to repository folders.

---

*End of record. Sections 4.2–4.7 await sign-off; Parts 3 and 4 are not yet started.*

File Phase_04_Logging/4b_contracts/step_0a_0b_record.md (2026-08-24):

# SDIGF — Server Tier Decision Journal

**Project:** Smart Decentralized Greenhouse (SDIGF)
**Repo:** `github.com/soul-taker-55/smart-decentralized-greenhouse`
**Last updated:** 2026-08-24

> This is a working journal, not a frozen document. It records what was built, what was decided
> and why, and what went wrong. It grows as the server tier is built and feeds the thesis chapters.
>
> The frozen interface specification lives separately at **`Contracts/mqtt_contract_v1.md`**.

---

## 1. Where the project stands

### The nine phases

| # | Name | Tier | Status |
|---|---|---|---|
| 1 | Wiring & bring-up | Edge | ✅ complete (wiring doc v1.7) |
| 2 | Standalone edge control | Edge | not started |
| 3 | Connectivity (MQTT) | Edge | not started |
| **4** | **Data & logging** | **Server** | **current** |
| 5a | Backend & dashboard | Server | |
| 5b | MCP server & chat | Server | |
| 6 | Access control, approval & signing | Server | |
| 7 | Fuzzy arbiter *(optional — only if logs justify)* | Edge | |
| 8 | Vision *(independent, any time after Phase 3)* | Server | |
| 9 | Ledger *(last)* | Server | |

Original dependency order: 1 → 2 → 3 → 4 → 5a → 5b → 6 → 7 → 9.

**Revised server-tier order:** 4 → 5a → 6 → 9 → 5b. The ledger needs signed events from Phase 6,
whereas MCP only wraps whatever API already exists — so the hardest server piece gets built
while there is still runway.

### Server-tier prep progress

```
0a  broker + DB + auth          ██████████  complete
0b  freeze MQTT contract        █████░░░░░  Parts 1–2 done
0c  mock edge simulator         ░░░░░░░░░░
4   DB + bridge + queries       ░░░░░░░░░░
```

Steps 0a–0c sit *underneath* Phase 4. They exist only because the server tier is being built
before the edge firmware, so a frozen interface and a fake ESP32 are needed to build against.

---

## 2. Step 0a — Infrastructure (COMPLETE)

### What is running

| Service | Image | Notes |
|---|---|---|
| `sdigf-db` | `timescale/timescaledb:latest-pg16` | Postgres 16 + TimescaleDB |
| `sdigf-emqx` | `emqx/emqx:latest` | v6.2.3, broker + dashboard |

Deployed as a **single Docker Compose stack** in Dokploy, sourced from GitHub at
`Phase_04_Logging/server/docker-compose.yml`, redeploying on push.

### Endpoints

| Purpose | Address | Exposure |
|---|---|---|
| EMQX dashboard (HTTP) | `eqmx.progrex.tech` | Traefik + TLS |
| MQTT broker (TCP 1883) | server IP / DNS A record | direct, **not** through Traefik |
| Postgres | internal Docker network only | not exposed |

### Server specification

11.7 GB RAM · 48 GB disk · CPU comfortably idle. TimescaleDB fits with room to spare.

### Verified

- ✅ Schema applied automatically on first boot — 10 tables
- ✅ TimescaleDB extension loaded
- ✅ Broker reachable from MQTTX
- ✅ **Retained message survives client disconnect/reconnect** (confirmed by the `Retained`
  badge in MQTTX). This is the behaviour the entire edge-reconnect design rests on.
- ✅ Authentication enabled — Built-in Database, password-based, SHA-256

### Broker accounts

| Username | Used by | Superuser |
|---|---|---|
| `sdigf-edge` | ESP32 firmware, and the Step 0c mock | No |
| `sdigf-bridge` | Phase 4 MQTT→DB bridge | No |
| `sdigf-backend` | Phase 5a REST backend | No |
| `sdigf-admin` | MQTTX / manual inspection | No |

Separate accounts are deliberate: Phase 6 ACLs attach to usernames. A single shared account
would have to be unpicked later. None are superusers — least privilege from the start.

---

## 3. Decisions and rationale

**EMQX instead of Mosquitto.** Mosquitto is lighter (~10 MB image / ~50 MB RAM vs ~200 MB /
~300 MB) and technically sufficient for one greenhouse. EMQX was chosen for its **built-in
management dashboard**, a stated project requirement. With 11.7 GB RAM available the overhead is
not material.

**TimescaleDB over InfluxDB.** One Postgres instance holds telemetry (hypertable), config
history, users, and the ledger. That means one backup, one connection string, and the ability to
JOIN telemetry against config events — which the Phase 4 conflict-frequency queries need.
InfluxDB would add a second stateful service and a second query language for no gain at this scale.

**MQTT is not routed through Traefik.** MQTT is raw TCP; Traefik here routes HTTP/HTTPS only.
The dashboard gets a Dokploy domain; the broker gets a plain DNS A record to the server IP.
*(This was attempted incorrectly twice before being resolved — worth remembering.)*

**Ledger as tables, not a service.** An append-only table with a `prev_hash` column and a trigger
rejecting UPDATE/DELETE is the entire mechanism. A separate service adds nothing until Phase 9
proves otherwise.

**Schema mounted from the repo, not downloaded at runtime.** Dokploy already clones the
repository on every deploy, so the schema file is on disk. Mounting `../db` into
`/docker-entrypoint-initdb.d` means Postgres applies it on first boot with no init script, no
network dependency, and no extra moving parts. An earlier design that fetched the schema from
GitHub at container start was unnecessary indirection.

**Contract documentation lives outside the phase tree.** The MQTT contract is built against by
Phase 3 firmware, Phase 4 bridge, Phase 5a backend, and the Step 0c mock. Filing it under
`Phase_04_Logging/` would force the firmware work to reach into a server phase for its own
interface spec. It sits in `Contracts/` instead, alongside the existing cross-cutting folders.

---

## 4. ⚠ Correction: the provisional database schema

A 10-table schema was written and applied to `sdigf_db` during Step 0a. **This was premature.**

Phase 4's schema should be *derived from* the frozen MQTT contract — field names, types, and
quality semantics all come from Step 0b. The applied tables are a reasonable skeleton but are
**provisional**. Expect column renames and type changes once contract Parts 3 and 4 are settled.

Ground-truth rule for this project: **the GitHub repository is canonical.** Uploaded files and
prior conversation content must never override it.

---

## 5. Deployment problems encountered

Recorded so they are not repeated, and because several are non-obvious.

| Symptom | Cause | Fix |
|---|---|---|
| `Compose file not found` | Path case/spelling mismatch against the real repo folder | Use the exact folder name: `Phase_04_Logging/server/docker-compose.yml` |
| `invalid interpolation format ... ${{project.VAR}}` | Dokploy UI syntax is invalid inside a git-stored compose file | Use standard `${VAR}` and set the value in Dokploy's Environment tab |
| `not a directory: mounting mosquitto.conf` | File absent from the repo, so Docker created an empty **directory** at that path | Ensure the file exists in git; delete the stray directory on the server before redeploying |
| `Unable to open pwfile` | Config referenced a `password_file` that was never created | Remove the reference, or create the file |
| `No such container: sdigf-db-1` | Dokploy prefixes container names | Get the real name from `docker ps` |
| `container is restarting, wait until running` | Crash loop — read the logs rather than trying to exec in | `docker logs <id> \| tail -50` |

**Operational note:** Dokploy's *Open Terminal* attaches to a **container**, not the host.
Host-level commands (`docker ps`, `docker volume rm`, pruning) require SSH.

**Postgres init only runs on an empty data volume.** This is correct behaviour — a redeploy must
not wipe live data — but it means that if a first attempt half-fails, the volume must be deleted
before retrying, or the second run silently skips initialization.

---

## 6. Server cleanup performed

Disk went from **29 GB → 19 GB used** (64% → 40%):

- 2.7 GB of archived systemd journals vacuumed
- ~7.2 GB of unused Docker images removed (old Dokploy version, EMQX leftover, dangling layers)
- Retired projects removed: exam-generator, hospital-management, osticket

Docker log rotation applied (`max-size 10m`, `max-file 3`) to prevent recurrence.

---

## 7. Open items

### Carried over from Step 0a

- [ ] **Broker-restart retention test.** What was verified is *client* reconnect. Restarting the
      broker container and confirming a retained message survives is a different guarantee — and
      it is the one the edge design actually depends on. **Do this before Phase 3.**
- [ ] **Backups.** Neither `sdigf_db_data` nor `sdigf_emqx_data` is backed up yet. Dokploy
      supports scheduled dumps and volume backups to S3-compatible storage.
- [ ] **`.gitignore` check.** Confirm `.env` and `*.env` are ignored. The compose file references
      `${POSTGRES_PASSWORD}`; one accidental commit puts the database password in permanent git
      history.

### Step 0b remaining

- [ ] **Part 3** — config payload structure (control parameters, arbiter policies)
- [ ] **Part 4** — canonical serialization spec + fixed test vector
- [ ] MQTTX test payloads for every topic, so the contract can be exercised by hand before either
      tier is written

### Backup recovery test worth doing early

Restore a dump to a scratch database and run the ledger chain-verification query — walk the
ledger, recompute each hash, confirm `prev_hash` links. If the chain validates after restore, the
backup is proven. The ledger's own integrity check doubles as backup verification, which is a
nice thing to be able to write up.

---

## 8. Working agreements

- **Ground truth:** the GitHub repository. Uploaded files and prior conversation never override it.
- Step-by-step with sign-off before code.
- Simple, direct language.
- Arabic documentation is maintained alongside English. The canonical Arabic term is
  **البيوت الزراعية الذكية**; **دفيئة** is never used.
- Thesis chapter structure maps to phases, which map to repository folders.

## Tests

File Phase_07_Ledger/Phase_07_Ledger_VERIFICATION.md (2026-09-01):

# PHASE 07 — INDEPENDENT VERIFICATION REPORT

**For the project planner.** Run in response to the pre-closure verification
request. Every result below is actual command output, not recollection.

**Verified against:** `origin/main` at `e224456`, freshly fetched.
**Environment:** clean clone of the public remote + local Postgres 16.15,
migrations 001–006 applied from the committed files.

> **RECOMMENDATION: DO NOT CLOSE ON THIS REPORT ALONE.**
> Three of the seven checks depend on the live VPS. I ran none of them. See §4,
> §7, and the caveat in §3.

---

## SUMMARY

| # | Check | Result |
|---|---|---|
| 1 | Everything pushed | ✅ **12 commits on origin** — working tree not checkable by me |
| 2 | Files exist in repo | ✅ all six, both halves of the split |
| 3 | Three §7 spec points | ✅ intact in the committed migration — live schema unchecked |
| 4 | Live chain verification | ⚠️ **NOT VERIFIED — no route to the VPS** |
| 5 | Tamper demo runs | ✅ six scenarios, full output |
| 6 | Tests without infrastructure | ✅ **88 pass, 0 skipped**, `SDIGF_TEST_DB` unset |
| 7 | Panel fix deployed | ⚠️ **committed, not confirmed deployed. No screenshot exists.** |

**One disagreement with the phase record — see §8.**

---

## 1 · IS IT ALL PUSHED?

```
$ git log --oneline 55e2b9f..origin/main
e224456 Phase 07: phase record
8f101f3 Phase 07: caveat at full weight - the requirement was met at half strength
1d22417 Phase 07: fix ledger panel - api.js returns an envelope and never throws
a5d6ca7 Phase 07: ledger verify endpoint and Activity panel - result, boundary and scope
cd4384e Phase 07: Tamper Demonstration - six scenarios against a disposable database
cf062f3 Phase 07: e-stop ledger append - best-effort, awaited after publish, never throws
f21bea3 Phase 07- Preparation
2edffce Phase 07: warn that the ledger's hashes depend on the INT8 type parser
443b2cf Phase 07: ledger tests - frozen time vectors, wire names, INT8 pin
a79feb7 Phase 07: ledger service - append, backfill, verifyChain
f7a8b34 Phase 07: pure link core - frozen wire names and time expression
9066097 Phase 07: ledger schema - explicit seq, no FKs, stored canonical
count: 12

$ git log origin/main --oneline -3
e224456 Phase 07: phase record
8f101f3 Phase 07: caveat at full weight - the requirement was met at half strength
1d22417 Phase 07: fix ledger panel - api.js returns an envelope and never throws
```

Twelve commits, `9066097` → `e224456`, all on the remote. The prior-loss scenario
is ruled out **for the remote**.

### ⚠ What I cannot check

`git status` on the operator's machine. My clone is of the public remote. If work
sits uncommitted in the working copy, only the operator can see it.

**Action: run `git status` locally and confirm a clean tree.**

---

## 2 · DO THE FILES EXIST IN THE REPO?

```
11577  Phase_05_Backend_Dashboard/5a_web/db/006_ledger.sql
 8450  Phase_05_Backend_Dashboard/5a_web/backend/src/ledger-link.js
19745  Phase_05_Backend_Dashboard/5a_web/backend/src/services/ledger-service.js
28387  Phase_05_Backend_Dashboard/5a_web/backend/tools/tamper-demo.mjs
16380  Phase_05_Backend_Dashboard/5a_web/backend/test/ledger-link.test.js
12129  Phase_07_Ledger/PHASE_07_RECORD.md
```

`ledger-link.js` (pure) and `services/ledger-service.js` (I/O shell) are **both
present** — the split forced by the import-time constraint.

---

## 3 · THE THREE §7 SPECIFICATION POINTS

Committed `006_ledger.sql` applied to a fresh database.

### Bugs 1 and 2 — no foreign keys

```sql
SELECT conname, contype FROM pg_constraint
 WHERE conrelid='ledger'::regclass AND contype='f';

 conname | contype
---------+---------
(0 rows)
```

Zero. `EVENT_MISSING` remains reachable; `prev_hash` can still store a broken chain
for the verifier to detect.

### Bug 2 — `seq` is not `BIGSERIAL`

```sql
SELECT column_name, column_default FROM information_schema.columns
 WHERE table_name='ledger' AND column_name='seq';

 column_name | column_default
-------------+----------------
 seq         |
(1 row)
```

Empty default. No sequence behind it. The hashed value cannot diverge from the
column value.

### UNIQUE constraints retained

```sql
        conname        | contype | pg_get_constraintdef
-----------------------+---------+----------------------
 ledger_entry_hash_key | u       | UNIQUE (entry_hash)
 ledger_event_id_key   | u       | UNIQUE (event_id)
```

`UNIQUE (event_id)` kept — it prevents two links claiming one event, a writer bug
rather than an attack. Only the `REFERENCES` was dropped.

### Bug 3 — check 5 and realTimeFrom precede the walk

From `services/ledger-service.js`:

```js
export async function verifyChain({ unchainedLimit = 100 } = {}) {
  const checkedAt = new Date().toISOString();
  const run = (t, p) => query(t, p);

  // ── Computed independently of the walk. See the warning above. ──
  const unchainedEvents = await findUnchainedEvents(unchainedLimit);

  const boundary = await query(
    `SELECT min(seq) AS real_time_from FROM ledger WHERE backfilled = false`
  );
  const realTimeFrom = boundary.rows[0].real_time_from ?? null;

  // ── The walk ──
  const links = await query(
    `SELECT seq, event_id, prev_hash, entry_hash, canonical, backfilled
       FROM ledger ORDER BY seq ASC`
  );
```

Two separate queries, both executed before `const links`. The walk's early return
cannot skip them.

**Demonstrated, not just inspected:** scenario 4 reports `PREV_MISMATCH` at seq 5
**and** `unchained events 4` from a single call — the walk broke and check 5 still
ran.

### ⚠ Caveat

This is the **committed migration**, not the live schema. A manual `ALTER TABLE`
on the VPS would not appear here.

**Action: run 3a–3c against `sdigf_backend` in the container.**

---

## 4 · DOES VERIFICATION PASS ON THE LIVE CHAIN?

### ⚠ NOT VERIFIED. I have no route to the VPS.

The endpoint requires an authenticated session cookie; my sandbox cannot reach
`greenhouse.progrex.tech`.

**The record's `ok true · length 59 · head 59 · realTimeFrom 58 · unchained 0` is
carried from an earlier run in the build session. It is NOT re-verified by this
report.**

**Action — run both:**

```bash
docker exec -i smart-greenhouse-project-sdigfserver-wyl2we-sdigf-db-1 \
  psql -U postgres -d sdigf_backend -c \
  "SELECT count(*), min(seq), max(seq), count(*) FILTER (WHERE backfilled) FROM ledger;"
```

Expect `59 | 1 | 59 | 57`.

Then `GET /api/ledger/verify` from a logged-in browser, or `curl` with the session
cookie. Paste the full body.

---

## 5 · DOES THE TAMPER DEMO RUN?

**Yes. All six scenarios, against a disposable database that the script creates
and drops itself.**

### The guard is stronger than requested

```js
const DB_NAME = 'sdigf_tamperdemo';
if (!DB_NAME.endsWith('_tamperdemo')) {
  console.error('refusing to run: target database name must end with _tamperdemo');
```

A hardcoded constant, not an environment variable. **There is no way to point it
at another database without editing the source** — stronger than "refuses one it
did not create."

### Results

| Scenario | Reported |
|---|---|
| 1 edit event field | `CONTENT_CHANGED` @seq 4, diff names `actor_id` (`eng-hala` → `eng-omar`) |
| 2 delete event | `EVENT_MISSING` @seq 4; restored byte-exactly, ok |
| 3 edit approval signature | `CONTENT_CHANGED` @seq 6, diff names `signature.signature` |
| 4 delete ledger link | `PREV_MISMATCH` @seq 5, **plus `unchained events 4`** |
| 5 delete link + event | `UNCHAINED_EVENT`, `unchained events 9` |
| 6 rewrite from genesis | **`ok`** — and that is the point |

### Scenario 6 closing evidence — both halves

```
BEFORE  9 links, ok
        1:KEY_REGISTERED  2:KEY_REGISTERED  3:APPROVAL_POLICY_CHANGED
        4:CONFIG_CREATED  5:CONFIG_PROPOSED  6:CONFIG_APPROVED
        7,8,9:COMMAND_ISSUED

ATTACK  erase CONFIG_CREATED, CONFIG_PROPOSED, CONFIG_APPROVED (ids 4,5,6)
        rebuild every link from genesis with buildLink()

AFTER   6 links, verification ok, unchained 0
        1:KEY_REGISTERED  2:KEY_REGISTERED  3:APPROVAL_POLICY_CHANGED
        4:COMMAND_ISSUED  5:COMMAND_ISSUED  6:COMMAND_ISSUED

        3 links and 3 events are gone. Verification reports ok.

WHAT SURVIVED THE REWRITE
  approval 1 by eng-omar (key eng-f7b45be3)
      decision      : approve
      re-verified   : VALID
      recomputed    : sha256(cfg_canonical) = eeda43af408f01281455e59b341d9620…
      stored        : cfg_hash             = eeda43af408f01281455e59b341d9620…
```

Ordering and narrative destroyed, chain clean, surviving signature **re-verified
VALID against its registered public key**. Both halves of "history can be
destroyed, approvals cannot be invented" are measured rather than asserted.

Note `realTimeFrom` reads `1` after the rewrite — **written by the attacker's own
rows.** This is the finding recorded in §6 of the phase record, reproduced here
by the demonstration itself.

---

## 6 · DO THE TESTS RUN WITHOUT INFRASTRUCTURE?

`SDIGF_TEST_DB` **unset**, no database reachable by the test process:

```
# tests 88
# pass 88
# fail 0
# skipped 0
```

**Zero skipped.** The assertions the split existed to protect all executed:

```
ok  1 - frozen vector: canonical string matches contract exactly
ok  2 - frozen vector: hash matches contract exactly
ok  3 - frozen vector: reproduces regardless of input key order
ok  4 - assertFrozenVector passes on the current implementation
ok 63 - frozen time format: the SQL expression is byte-exact
ok 64 - frozen time format: the vectors are the ones verified against Postgres 16
ok 65 - frozen time format: fixed width — microseconds always six digits
ok 73 - INT8 PIN: a string event_id produces a different hash than a numeric one
ok 74 - INT8 PIN: the same applies to ref_id and to approval_id
```

The pure/shell split holds. The most important tests are not the most often
skipped.

---

## 7 · THE PANEL FIX

### ⚠ Committed, NOT confirmed deployed. No screenshot exists.

Commit `8f101f3` is on the remote: caveat body `--muted` → `--text`, size
`0.85rem` → `0.9rem`, separator `--line` → `--muted`, padding 10 → 12.

**Committed is not deployed, and deployed is not photographed.** The figure for
Chapter 12 does not exist yet.

**Action: redeploy `sdigfbackend`, open Activity in incognito, capture.**

---

## 8 · DISAGREEMENT WITH THE PHASE RECORD

**One. About status, not content.**

§3 of `PHASE_07_RECORD.md` lists under **VERIFIED LIVE**:

> Endpoint + panel — rendering at `greenhouse.progrex.tech/events`

True when written — but written **before** `8f101f3`, the caveat-prominence fix.
The panel currently deployed is the half-strength version. The record reads as
though the corrected panel is live; **it is committed, not deployed.**

Suggested amendment: move that row to a third state, or annotate it
*"panel rendering live as of `1d22417`; caveat-prominence fix `8f101f3` committed,
deployment unconfirmed."*

Nothing else disagrees. Checks 1, 2, 3, 5 and 6 confirm the record as written.

---

## 9 · WHAT MUST HAPPEN BEFORE CLOSURE

1. `git status` locally — confirm a clean working tree (§1)
2. Run the three schema queries against **live** `sdigf_backend` (§3)
3. Run the live chain queries and the endpoint (§4)
4. Redeploy, capture the panel screenshot (§7)
5. Amend the phase record per §8

Four of these are live-system actions I cannot perform. Until they are done, this
report verifies the **repository**, not the **deployment**.

---

## ACKNOWLEDGEMENT

The instruction to verify independently rather than report from memory was the
right call, and it found something: the record's live-panel claim is stale by one
commit. That is exactly the drift class this project has caught repeatedly by
checking rather than accepting a handoff — three stale claims and two phantom
defects across earlier sessions, and now a sixth.

It also surfaced the boundary of what I can verify at all. Three of seven checks
need the live system, and reporting them as passed on the strength of an earlier
session would have been precisely the failure the instruction guards against.
They are marked NOT VERIFIED rather than softened.

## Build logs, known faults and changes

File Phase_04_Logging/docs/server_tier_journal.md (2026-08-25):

# SDIGF — Server Tier Decision Journal

**Project:** Smart Decentralized Greenhouse (SDIGF)
**Repo:** `github.com/soul-taker-55/smart-decentralized-greenhouse`
**Last updated:** 2026-08-25

> This is a working journal, not a frozen document. It records what was built, what was decided
> and why, and what went wrong. It grows as the server tier is built and feeds the thesis chapters.
>
> The frozen interface specification lives at
> **`Phase_04_Logging/4b_contracts/mqtt_contract_v3.md`**.

> **Numbering note.** This document was originally written under a nine-phase scheme
> (`Phase 1–9`, with sub-steps `0a`/`0b`/`0c`) and was filed as `step_0a_0b_record.md`. The project
> has since renumbered to **00–08**. All references below use the corrected scheme. If you find a
> stale `Step 0a` or `Phase 9` anywhere in the repo, it predates 2026-08-25 and should be fixed.

---

## 1. Where the project stands

### The phases

| # | Name | Tier | Status |
|---|---|---|---|
| 00 | Prototype | Edge | ✅ complete |
| 01 | Hardware Architecting | Edge | ✅ complete (wiring doc v1.7) |
| 02 | Standalone Edge Control | Edge | in progress — firmware not yet written |
| 03 | Connectivity (MQTT) | Edge | blocked by 02 |
| **04** | **Logging** | **Server** | **current** |
| 05a | Web — REST API + dashboard | Server | next |
| 05b | RBAC, approval, signing | Server | |
| 05c | MCP server + chat | Server | |
| 06 | Vision (ESP32-CAM) *(independent)* | — | |
| 07 | Ledger | Server | |
| 08 | Fuzzy arbiter *(optional — only if logs justify)* | Edge | |

**Server-tier build order:** 04 → 05a → 05b → 07 → 05c.

The ledger (07) needs signed events from 05b, whereas MCP (05c) only wraps whatever API already
exists — so the hardest server piece gets built while there is still runway.

### Phase 04 progress

```
04a  broker + DB + auth          ██████████  complete
04b  freeze MQTT contract        ██████████  v3 frozen; v4 amendment in progress
04c  mock edge simulator         ██████████  Stage 1 complete
04d  MQTT→Postgres bridge        ██████████  complete, deployed, verified
     conflict queries            ░░░░░░░░░░  blocked — see §8
```

Steps 04a–04c sit *underneath* Phase 04. They exist only because the server tier is being built
before the edge firmware, so a frozen interface and a fake ESP32 are needed to build against.

---

## 2. Step 04a — Infrastructure (COMPLETE)

### What is running

| Service | Image | Notes |
|---|---|---|
| `sdigf-db` | `timescale/timescaledb:2.17.2-pg16` | Postgres 16 + TimescaleDB |
| `sdigf-emqx` | `emqx/emqx:6.2.3` | Broker + dashboard |

Deployed as a **single Docker Compose stack** in Dokploy, sourced from GitHub at
`Phase_04_Logging/4a_server_emqx/docker-compose.yml`, redeploying on push.

**Both images are pinned.** They were originally `latest` / `latest-pg16`. On a project spanning
months, `latest` means a silent major upgrade can land mid-thesis with no record of when or why —
and on a broker, a config-schema change between versions could break the deployment during an
unrelated redeploy.

**The broker is EMQX Enterprise, not the open-source edition.** `emqx ctl broker` reports
`sysdescr: EMQX Enterprise`. This was not a deliberate choice — it is what the `emqx/emqx` tag
resolves to. Different licence terms apply, and the thesis must state the edition accurately
rather than referring to "EMQX" unqualified.

### Endpoints

| Purpose | Address | Exposure |
|---|---|---|
| EMQX dashboard (HTTP) | `eqmx.progrex.tech` | Traefik + TLS |
| MQTT broker (TCP 1883) | server IP / DNS A record | direct, **not** through Traefik |
| Postgres | internal Docker network only | not exposed |

Internal service names on `dokploy-network`: `sdigf-db:5432`, `sdigf-emqx:1883`.

### Server specification

11.7 GB RAM · 48 GB disk · CPU comfortably idle. TimescaleDB fits with room to spare.

### Verified

- ✅ Schema applied automatically on first boot
- ✅ TimescaleDB extension loaded
- ✅ Broker reachable from MQTTX
- ✅ Retained message survives **client** disconnect/reconnect
- ✅ Retained message survives **broker restart** — but only after a configuration fix. The
  default failed. See §5. This is a distinct guarantee from client reconnect and only the first
  had ever been tested.
- ✅ Authentication enabled — Built-in Database, password-based, SHA-256

### Broker accounts

| Username | Used by | Superuser |
|---|---|---|
| `sdigf-edge` | ESP32 firmware, and the 04c mock | No |
| `sdigf-bridge` | 04d MQTT→DB bridge | No |
| `sdigf-backend` | 05a REST backend | No |
| `sdigf-admin` | MQTTX / manual inspection | No |

Separate accounts are deliberate: 05b ACLs attach to usernames. A single shared account would
have to be unpicked later. None are superusers.

**However — no topic authorization is currently enforced.** See §6. The accounts are separated
*in preparation for* 05b ACLs; they do not yet constrain what any account may publish or
subscribe to.

---

## 3. Step 04c — Mock edge simulator (Stage 1 COMPLETE)

`Phase_04_Logging/4c_tool/mock-edge/`, deployed as its own Dokploy stack `sdigf-mock`.

Publishes telemetry, health and status on the frozen contract. Stage 1 scope: connect, last will,
telemetry, static actuator state. **Not** implemented: physics, control loop, config handling,
safety envelope, failure simulation.

**Currently stopped**, deliberately — see §8.

---

## 4. Step 04d — MQTT→Postgres bridge (COMPLETE)

`Phase_04_Logging/4d_bridge/`, deployed as its own Dokploy stack `sdigf-bridge`. Node.js.

Subscribes to all five edge→server topics and writes to `telemetry`, `actuator_state` and
`edge_events`.

**Read-only by design.** It does not subscribe to `down/config` or `down/cmd` and publishes
nothing at all. Command publication belongs to 05a's service layer. This is what allows the claim
that the logging tier has no code path to an actuator — an absence of code, not a policy that
could be relaxed.

**Not in the control path.** If the bridge dies the greenhouse keeps running; only the record is
lost. That is the tier split working as designed.

Full design notes are in the bridge's own `README.md`. The two worth repeating here:

- **`time` is always the bridge's receipt time.** The device clock is preserved in `device_ts`
  with `ts_quality`, but never drives the time axis. Using the device clock when trustworthy and
  receipt time otherwise would produce a column whose meaning changes with a flag in another
  column, and any aggregate spanning a reboot would silently mix the two.
- **Dedup needs an explicit check, not just the unique index.** The contract requires uniqueness
  on `(greenhouse_id, seq, sensor_name)`, but TimescaleDB forces `time` into any unique index —
  and because `time` is receipt time, a QoS 1 redelivery arrives at a different instant and
  produces a different key. The bridge therefore queries a 60-minute window before writing.
  DB-backed, so it survives a bridge restart, which is exactly when redelivery happens.

Tested before deployment against a live broker and a Postgres instance loaded with the real
schema: 24 parser unit tests, full message flow, duplicate suppression, database-outage buffering
with exponential backoff, malformed input, reboot inference. Then verified again in place after
deployment.

---

## 5. ⚠ Retained messages are not durable by default — FINDING

**Discovered 2026-08-25 while closing a carried-over open item.**

EMQX defaults `retainer.backend.storage_type` to **`ram`**. Retained messages are held in memory
only and are destroyed when the broker restarts. Confirmed on this deployment:

```
retainer { backend { storage_type = ram } }
```

### Why it matters

`down/config` is retained precisely so a reconnecting ESP32 receives the current configuration
without the server having to detect the reconnection and re-push. The contract states this
plainly. With `ram` storage that guarantee holds for *client* reconnects and fails after a
*broker* restart — two different things that had been conflated.

The failure is quiet. Broker restarts → retained config is gone → ESP32 reboots later → connects
→ receives nothing → continues on NVS last-known-good indefinitely, because nothing in the current
design republishes config after a broker restart. The greenhouse keeps running and
`cfg.src = "nvs"` makes it visible in the data — the autonomy design absorbs it exactly as
intended. But an operator who has just approved a setpoint change sees it marked applied while the
device is still on the old one.

### Fix

`EMQX_RETAINER__BACKEND__STORAGE_TYPE: disc` in the 04a compose environment.

Changing `storage_type` on an existing mnesia table may not migrate automatically. If the retained
count reads zero straight after the change, clear the retainer and republish rather than assuming
the setting failed.

### The architectural lesson, which is the part worth writing up

The setting is a footnote. The principle is not: **retained messages are broker-held state, and
broker state is not durable by default.** The server must be able to reconstruct every retained
topic from its own database.

So **05a republishes the current approved config on startup and on broker reconnect**, treating
the retained message as a cache rather than a source of truth. This is the same reasoning as the
edge safety envelope — do not assume infrastructure you do not control got it right — and it is a
second independent instance of the project's central principle rather than a one-off bug fix.

---

## 6. ⚠ No topic authorization is enforced — FINDING

**Discovered 2026-08-25, immediately after the retention fix.**

`authorization.no_match = deny` is set, which is the correct posture. But the ACL source is
`${EMQX_ETC_DIR}/acl.conf`, and that file still ends with EMQX's shipped default:

```erlang
{allow, {security_profile, legacy}}.
```

On EMQX 6.2.3 the security profile defaults to `legacy`, so this rule **matches and allows
everything**. `no_match = deny` is never reached, because the catch-all fires first. EMQX's own
comment in the file states the production fix: change the last rule to `{deny, all}.`

**Consequence.** Any authenticated account can publish or subscribe to any topic. `sdigf-bridge`
could publish to `down/config` right now. The bridge's read-only property still holds — it is
enforced by an absence of code — but that is a weaker guarantee than a broker-level restriction,
and the journal previously claimed "least privilege from the start", which was not accurate.

**`deny_action = ignore` compounds it.** When a publish *is* eventually denied, EMQX drops the
message silently and returns success to the client. No error, no disconnect. This is the exact
failure mode that wasted time during the retention test: a `mosquitto_pub` that appeared to
succeed while the broker discarded it.

The place this will bite hardest is 05a. If the backend publishes `down/config` with a credential
that lacks permission, the API returns 200, the dashboard reports "applied", and the ESP32 never
receives anything — and it would be debugged as a firmware or network fault for hours before the
broker was suspected.

**Planned resolution (05b).** Write per-account ACL rules against the frozen topic tree and change
the final rule to `{deny, all}.` Two things must accompany that change:

- Set `deny_action = disconnect` at least during development, so a denied publish is loud rather
  than silent.
- 05a verifies config delivery by subscribing to its own `down/config` and reading the retained
  message back, rather than trusting that publish succeeded. This is the same
  reconstruct-from-your-own-database principle as §5, and it covers both failure modes at once.

Not treated as urgent: ACLs were always a 05b deliverable, and a wrong ACL written today would
break the running bridge silently given `deny_action = ignore`. Recorded here so the gap is a
known scheduled item rather than an unexamined assumption.

---

## 7. Decisions and rationale

**EMQX instead of Mosquitto.** Mosquitto is lighter (~10 MB image / ~50 MB RAM vs ~200 MB /
~300 MB) and technically sufficient for one greenhouse. EMQX was chosen for its **built-in
management dashboard**, a stated project requirement. With 11.7 GB RAM available the overhead is
not material.

**TimescaleDB over InfluxDB.** One Postgres instance holds telemetry (hypertable), config history,
users, and the ledger. That means one backup, one connection string, and the ability to JOIN
telemetry against config events — which the Phase 04 conflict-frequency queries need. InfluxDB
would add a second stateful service and a second query language for no gain at this scale.

**MQTT is not routed through Traefik.** MQTT is raw TCP; Traefik here routes HTTP/HTTPS only. The
dashboard gets a Dokploy domain; the broker gets a plain DNS A record to the server IP.
*(This was attempted incorrectly twice before being resolved — worth remembering.)*

**Ledger as tables, not a service.** An append-only table with a `prev_hash` column and a trigger
rejecting UPDATE/DELETE is the entire mechanism. A separate service adds nothing until Phase 07
proves otherwise.

**Schema mounted from the repo, not downloaded at runtime.** Dokploy already clones the repository
on every deploy, so the schema file is on disk. Mounting `../db` into
`/docker-entrypoint-initdb.d` means Postgres applies it on first boot with no init script, no
network dependency, and no extra moving parts. An earlier design that fetched the schema from
GitHub at container start was unnecessary indirection.

**A custom bridge rather than EMQX's built-in rule engine + Postgres sink.** EMQX can pipe MQTT
into Postgres with no code, and for `status` or a plain `health` insert it would genuinely be
simpler. It was rejected because the pieces that make it simple are a minority of what this bridge
does. The null rule is conditional per-field logic across eleven sensors; one telemetry message
must fan out to eleven rows from a fixed object rather than an array, which `foreach` cannot
iterate; dedup needs a lookup before the insert decision; and reboot inference needs state across
messages, which a per-message rule engine does not hold. Beyond that, a visible bridge with an
explicit contract-to-schema mapping is defensible line by line in a viva, whereas "the vendor's
rule engine did it" is a black box in the architecture chapter. In a production system with no
thesis requirement and a 1:1 field mapping, the built-in sink would be the right call.

---

## 8. Deployment problems encountered

Recorded so they are not repeated, and because several are non-obvious.

| Symptom | Cause | Fix |
|---|---|---|
| `Compose file not found` | Path case/spelling mismatch against the real repo folder | Use the exact folder name |
| `EISDIR: illegal operation on a directory, read` | Dokploy's Compose Path pointed at the folder, not the file | Set it to `…/4d_bridge/docker-compose.yml` |
| `invalid interpolation format ... ${{project.VAR}}` | Dokploy UI syntax is invalid inside a git-stored compose file | Use standard `${VAR}` and set the value in Dokploy's Environment tab |
| `not a directory: mounting mosquitto.conf` | File absent from the repo, so Docker created an empty **directory** at that path | Ensure the file exists in git; delete the stray directory on the server before redeploying |
| `Unable to open pwfile` | Config referenced a `password_file` that was never created | Remove the reference, or create the file |
| `No such container: sdigf-db-1` | Dokploy prefixes container names | Get the real name from `docker ps` |
| `container is restarting, wait until running` | Crash loop — read the logs rather than trying to exec in | `docker logs <id> \| tail -50` |
| Env var change appeared not to apply | Container needs a **redeploy**, not a restart, to pick up a new value | Redeploy after editing the Environment tab |
| Bridge logged no `subscribed` lines after a broker restart | **Not a fault.** mqtt.js short-circuits `subscribe()` when every topic is already in its internal resubscribe table, invoking the callback with an empty `granted` array and sending no SUBSCRIBE packet. Messages were still arriving — proved by publishing after the restart and seeing the rows land. | Bridge now logs `sessionPresent` and states explicitly when no SUBSCRIBE was re-sent. Silence had read exactly like failure and cost real diagnosis time. |

**Operational note:** Dokploy's *Open Terminal* attaches to a **container**, not the host.
Host-level commands (`docker ps`, `docker volume rm`, pruning) require SSH.

**Postgres init only runs on an empty data volume.** This is correct behaviour — a redeploy must
not wipe live data — but it means that if a first attempt half-fails, the volume must be deleted
before retrying, or the second run silently skips initialization.

---

## 9. Why data collection has not started

The mock is deployed and working, and the bridge is deployed and verified, but **`sdigf-mock` is
deliberately stopped and the live tables are empty.**

The reason is not caution about infrastructure. It is that **the mock's actuators publish static
`off` states** — Stage 1 explicitly excludes control logic. There is no rule arbiter behind it, so
nothing is deciding to suppress or alternate anything.

That means Conflict A (fans vs. humidifier) and Conflict B (canopy vs. photoperiod) cannot occur
in the current data at all. Running the mock for a week today would produce infrastructure
verification, not the dataset the Phase 04 done-condition requires.

**Real conflict-frequency data is a Phase 02 dependency**, not something achievable by running the
current mock longer. Phase 04 cannot be marked fully complete until firmware — or a Stage 2+ mock
carrying arbiter logic — produces real actuator decisions.

**Phase 08 (fuzzy arbiter) is explicitly out of scope for now.** No fuzzy-vs-rule-arbiter
evaluation is being attempted at this stage, and it should not surface as an open question in 05a
or 05b work.

---

## 10. Correction: the provisional database schema — RESOLVED

The original 10-table schema written during 04a was flagged here as **provisional**, because Phase
04's schema should be *derived from* the frozen contract rather than guessed ahead of it.

**That correction has now been applied.** `Phase_04_Logging/db/sdigf-db-schema-v2.sql` aligns the
schema to contract v3 and is the version running. Five mismatches were fixed:

1. `telemetry.value` made nullable — the contract's null rule requires `val = null` when quality
   is `fail` or `init`, and a sentinel like `0` or `-127` leaks into averages
2. Quality flags corrected to lowercase `ok`/`stale`/`fail`/`init`, with `init` added
3. `seq` column added — required for deduplication
4. `device_ts` / `ts_quality` separated from `time`
5. `actuator_state` table added — the conflict queries cannot be answered without it

Also added: `edge_events`, and `telemetry_archive` / `actuator_state_archive` as plain tables with
no retention or compression policy attached. The live tables are operational data governed by
policy; the archives are evidence, governed by nothing. If the thesis dataset lived in a table with
a retention policy, a single configuration change months from now could delete the observations an
argument rests on — silently, with no error.

The superseded schema is retained at `Phase_04_Logging/db/old/sdigf-db-schema.sql` as a record of
what changed. It is inert: Postgres's init entrypoint globs files, not directories.

**Ground-truth rule for this project: the GitHub repository is canonical.** Uploaded files and
prior conversation content must never override it.

---

## 11. Open items

### Resolved 2026-08-25

- [x] **Broker-restart retention test.** Tested and **failed** — EMQX defaulted the retainer to
      `storage_type = ram`. Fixed by setting `disc` in the 04a compose. See §5. Client-reconnect
      retention was verified in 04a and remains valid; the two are separate guarantees and only
      the first had ever been tested. The journal was right to keep this open, and a later session
      record claiming both had passed was mistaken.
- [x] **`.gitignore` check.** `.env` is ignored at root and in `mock-edge` and `4d_bridge`. No
      `.env` is reachable in the public repo. Every committed compose file uses interpolation only
      — `${POSTGRES_PASSWORD}`, `${MQTT_PASS}`, `${PG_PASS}` — with no literals anywhere.
      **One gap found and fixed:** root `.gitignore` had `.env` but not `*.env`, so a file named
      `prod.env` would have been committed.
- [x] **Retention re-verified after the `disc` change.** Published a retained message to
      `sdigf/v1/gh1/test/retain`, restarted the broker, confirmed via `emqx ctl retainer topics`
      that it survived. Note `retainer info` counts `$SYS/` topics too, so the raw count is
      misleading — list the topics rather than trusting the number.
- [x] **04b Part 3** — config payload structure (control parameters, arbiter policies)
- [x] **04b Part 4** — canonical serialization spec + frozen test vector

### Open

- [ ] **Backups.** Neither `sdigf_db_data` nor `sdigf_emqx_data` is backed up. Dokploy supports
      scheduled dumps and volume backups to S3-compatible storage. This is now the largest
      unmitigated risk on the server tier — the thesis dataset will live in these volumes.
- [ ] **Contract v4** — edge-side signature verification. ECDSA P-256; `ver` and `gh` moved inside
      the signed content to close a replay/downgrade hole; `cfg_canonical` replaces `cfg`;
      `verify` declared by the edge, never supplied by the server.
- [ ] **Broker ACLs (05b).** No topic authorization is currently enforced — see §6. Write
      per-account rules against the frozen topic tree, change the final `acl.conf` rule to
      `{deny, all}.`, and set `deny_action = disconnect` during development.
- [ ] **Rotate the `sdigf-admin` password.** It was pasted in plaintext during the 2026-08-25
      retention testing session and is in shell history.
- [ ] **MQTTX test payloads** for every topic, so the contract can be exercised by hand before
      either tier is written
- [ ] **Second SHA-256 test vector** using the real config shape, once the agriculture engineer
      supplies actual values

### Backup recovery test worth doing early

Restore a dump to a scratch database and run the ledger chain-verification query — walk the ledger,
recompute each hash, confirm `prev_hash` links. If the chain validates after restore, the backup is
proven. The ledger's own integrity check doubles as backup verification, which is a nice thing to
be able to write up.

---

## 12. Working agreements

- **Ground truth:** the GitHub repository. Uploaded files and prior conversation never override it.
- Step-by-step with sign-off before code.
- Simple, direct language.
- Arabic documentation is maintained alongside English. The canonical Arabic term is
  **البيوت الزراعية الذكية**; **دفيئة** is never used.
- Thesis chapter structure maps to phases, which map to repository folders.

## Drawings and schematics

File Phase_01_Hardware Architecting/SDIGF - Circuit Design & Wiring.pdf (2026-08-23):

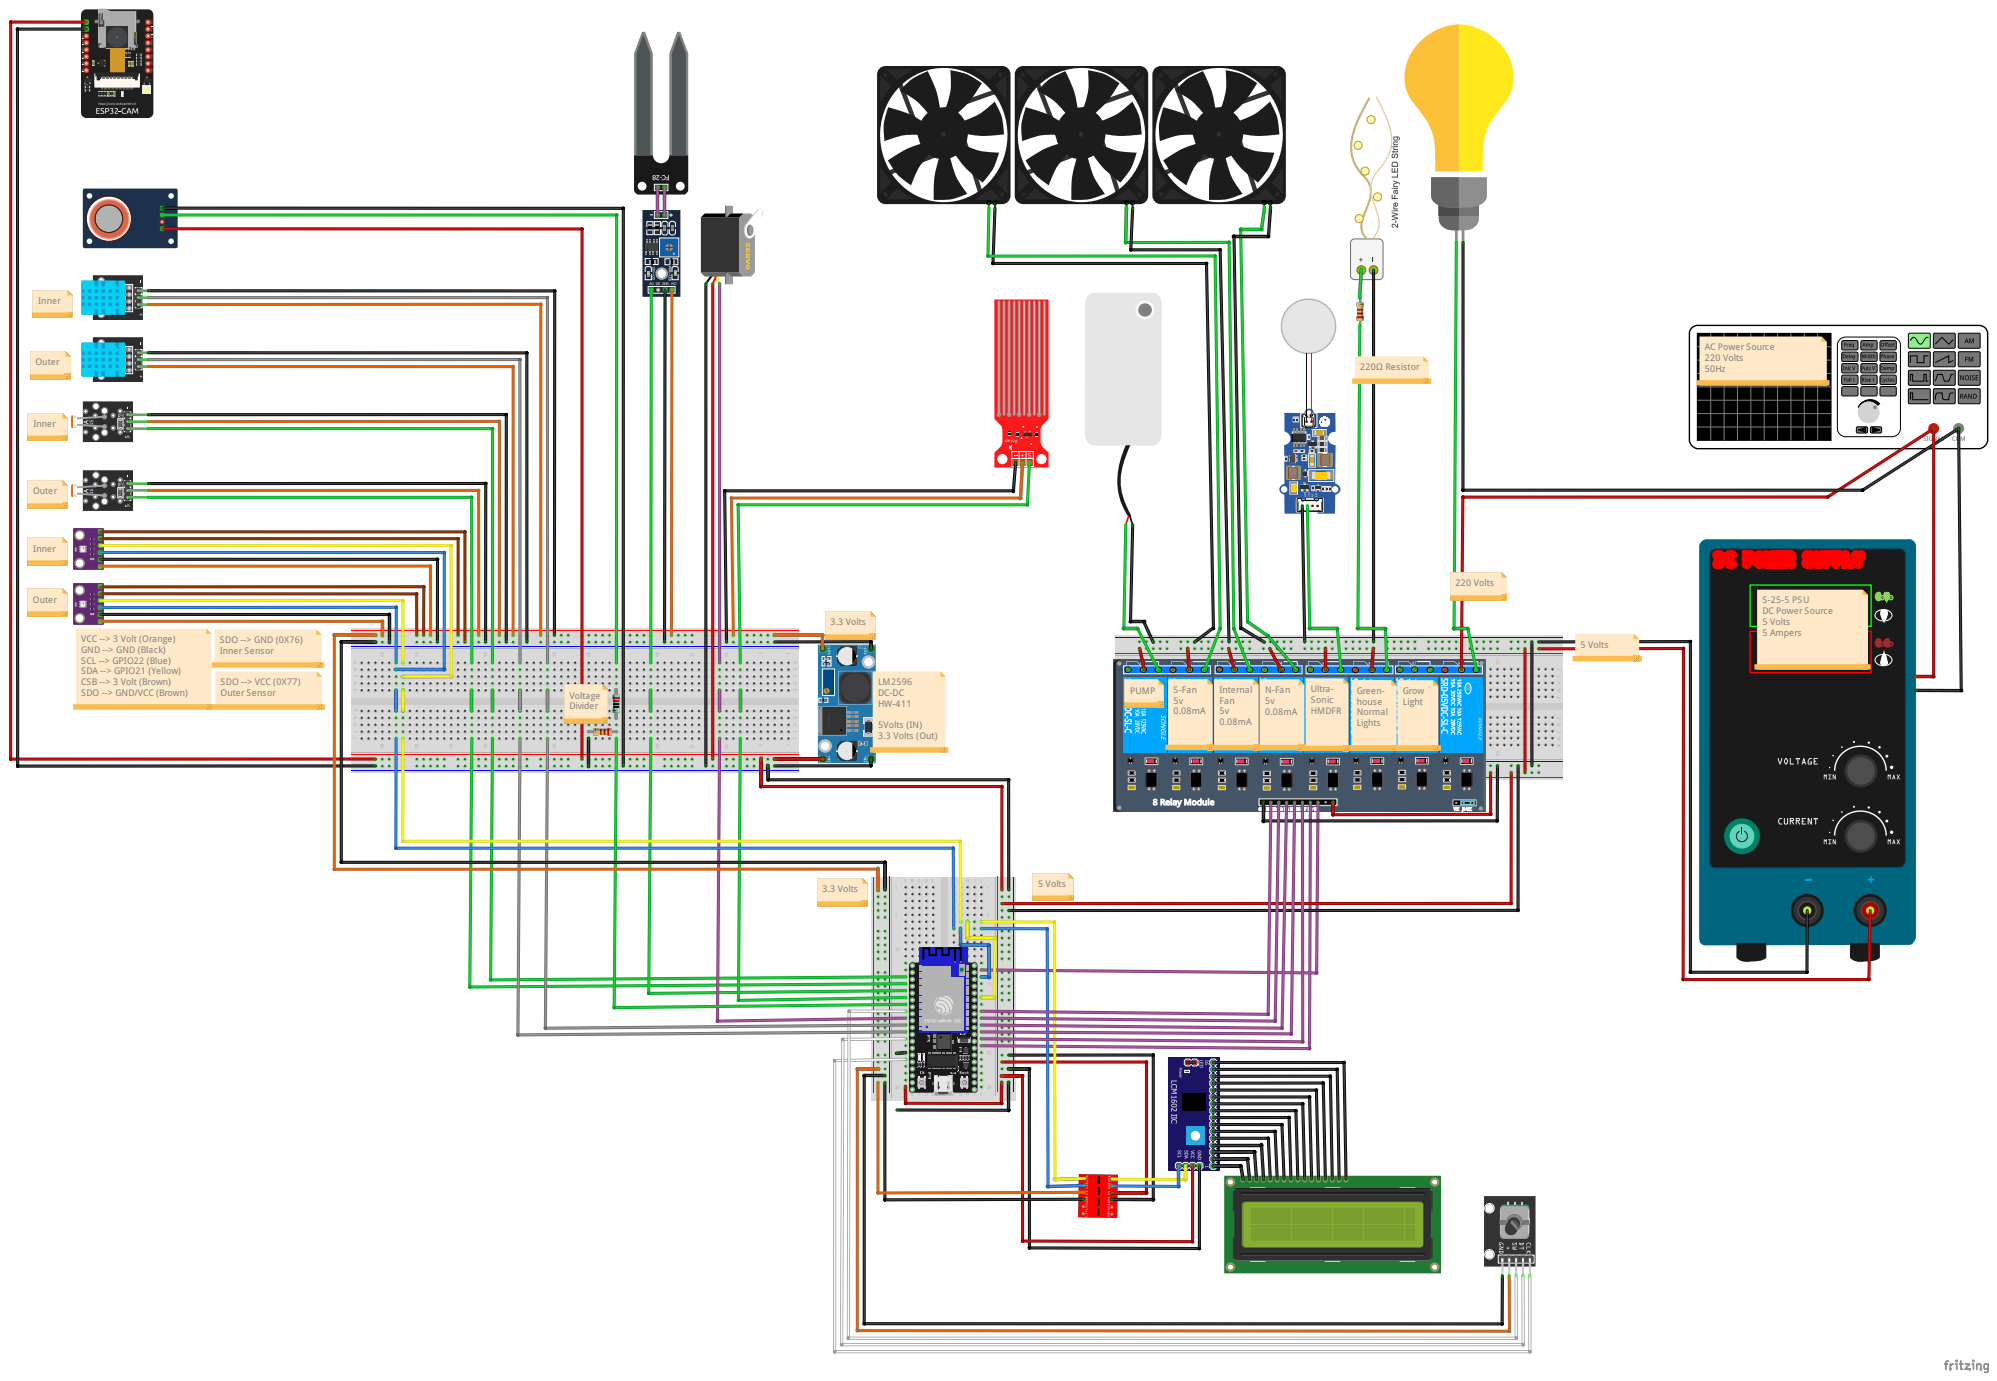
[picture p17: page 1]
Outer; Inner; 220Ω Resistor; Voltage Divider; AC Power Source 220 Volts 50Hz; 220 Volts; 5Volts (IN) 3.3 Volts (Out); 3.3 Volts; 5 Volts; Internal Fan 5v 0.08mA; N-Fan 5v 0.08mA; Green- house Normal Lights; Grow Light; Ultra- Sonic HMDFR; S-Fan 5v 0.08mA; PUMP; SDO --> VCC (0X77) Outer Sensor; SDO --> GND (0X76) Inner Sensor

S-25-5 PSU
DC Power Source
5 Volts
5 Ampers

VCC --> 3 Volt (Orange)
GND --> GND (Black)
SCL --> GPIO22 (Blue)
SDA --> GPIO21 (Yellow)
CSB --> 3 Volt (Brown)
SDO --> GND/VCC (Brown)

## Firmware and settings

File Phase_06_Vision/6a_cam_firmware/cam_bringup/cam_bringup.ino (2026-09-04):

// SDIGF Phase 06 — CAM: capture, software JPEG, upload to server.
// Board: AI-Thinker ESP32-CAM layout. Sensor: OV7670-class (PID 0x2145),
// no hardware JPEG encoder — software encode via frame2jpg() is the
// documented workaround, not a design preference. See Phase 06 chapter notes.
//
// Two capture paths, independent of each other:
//   SCHEDULED — one frame per day, the growth-tracking timelapse. This is what
//               builds the dataset; it must not depend on anyone being present.
//   REQUESTED — the dashboard's snapshot button sets a flag in the database.
//               The server CANNOT REACH THIS DEVICE (NAT, no inbound port), so
//               the flag is something the camera asks about on its own poll
//               interval, never something pushed to it. That constraint is the
//               reason for polling, not a shortcut.
//
// KNOWN GAP, stated plainly rather than hidden: TLS certificate validation is
// OFF (WiFiClientSecure::setInsecure()). The endpoint only accepts image
// uploads gated by a bearer token; a MITM here can see or drop a JPEG, not
// reach any actuator or control-path route. Certificate pinning against
// greenhouse.progrex.tech is real future work, not silently skipped.

#include <Arduino.h>
#include <WiFi.h>
#include <WiFiClientSecure.h>
#include <HTTPClient.h>
#include <time.h>
#include "esp_camera.h"
#include "img_converters.h"
#include "secrets.h"

// ---- AI-Thinker pin map (fixed by the board, not a choice) ----
#define PWDN_GPIO_NUM     32
#define RESET_GPIO_NUM    -1
#define XCLK_GPIO_NUM      0
#define SIOD_GPIO_NUM     26
#define SIOC_GPIO_NUM     27
#define Y9_GPIO_NUM       35
#define Y8_GPIO_NUM       34
#define Y7_GPIO_NUM       39
#define Y6_GPIO_NUM       36
#define Y5_GPIO_NUM       21
#define Y4_GPIO_NUM       19
#define Y3_GPIO_NUM       18
#define Y2_GPIO_NUM        5
#define VSYNC_GPIO_NUM    25
#define HREF_GPIO_NUM     23
#define PCLK_GPIO_NUM     22

#define FLASH_LED_PIN      4
#define USE_FLASH       true
#define FLASH_MS         120

#define JPEG_QUALITY      80

// ── INTERVALS ───────────────────────────────────────────────────────────
// One scheduled frame per day. Plants change over days and weeks; a frame a
// day is enough resolution to see growth and cheap enough to keep for a season
// (~7 KB each, ~2.5 MB a year). Manual snapshots add to whatever day they land
// on, so a day can hold one frame or several.
//
// For bench testing, drop this to something short — e.g. 60UL * 1000UL — but
// put it back before leaving the device to run.
#define SCHEDULE_INTERVAL_MS (24UL * 60UL * 60UL * 1000UL)

// How often to ask the server whether a snapshot has been requested. 10s is
// responsive enough that the button does not feel broken, and cheap: the poll
// is a ~200-byte GET, not an image.
#define POLL_INTERVAL_MS (10UL * 1000UL)

// Server endpoint. Not secret — kept here rather than in secrets.h so
// changing environments (bench vs deployed) doesn't touch the file that
// holds WiFi and device credentials.
#define UPLOAD_URL  "https://greenhouse.progrex.tech/api/camera/upload"
#define PENDING_URL "https://greenhouse.progrex.tech/api/camera/pending"

static uint32_t frameCount = 0;
static uint32_t uploadOk = 0;
static uint32_t uploadFail = 0;

const char* sensorName(uint16_t pid) {
  switch (pid) {
    case 0x26:   return "OV2640 (hardware JPEG)";
    case 0x2145:
    case 0x76:   return "OV7670-class (no hardware JPEG)";
    case 0x77:   return "OV7725 (no hardware JPEG)";
    case 0x36:   return "OV3660";
    case 0x56:   return "OV5640";
    default:     return "unknown";
  }
}

bool initCamera() {
  camera_config_t c;
  c.ledc_channel = LEDC_CHANNEL_0;
  c.ledc_timer   = LEDC_TIMER_0;
  c.pin_d0 = Y2_GPIO_NUM;   c.pin_d1 = Y3_GPIO_NUM;
  c.pin_d2 = Y4_GPIO_NUM;   c.pin_d3 = Y5_GPIO_NUM;
  c.pin_d4 = Y6_GPIO_NUM;   c.pin_d5 = Y7_GPIO_NUM;
  c.pin_d6 = Y8_GPIO_NUM;   c.pin_d7 = Y9_GPIO_NUM;
  c.pin_xclk = XCLK_GPIO_NUM;
  c.pin_pclk = PCLK_GPIO_NUM;
  c.pin_vsync = VSYNC_GPIO_NUM;
  c.pin_href  = HREF_GPIO_NUM;
  c.pin_sccb_sda = SIOD_GPIO_NUM;
  c.pin_sccb_scl = SIOC_GPIO_NUM;
  c.pin_pwdn  = PWDN_GPIO_NUM;
  c.pin_reset = RESET_GPIO_NUM;
  c.xclk_freq_hz = 10000000;
  c.pixel_format = PIXFORMAT_RGB565;
  c.frame_size   = FRAMESIZE_QVGA;
  c.jpeg_quality = 12;
  c.fb_count     = psramFound() ? 2 : 1;
  c.grab_mode    = CAMERA_GRAB_LATEST;
  c.fb_location  = psramFound() ? CAMERA_FB_IN_PSRAM : CAMERA_FB_IN_DRAM;

  esp_err_t err = esp_camera_init(&c);
  if (err != ESP_OK) {
    Serial.printf("[CAM] init FAILED 0x%02X\n", err);
    return false;
  }

  sensor_t *s = esp_camera_sensor_get();
  if (s != NULL) {
    Serial.printf("[CAM] sensor PID 0x%02X = %s\n", s->id.PID, sensorName(s->id.PID));
  }
  Serial.println("[CAM] init OK");
  return true;
}

/**
 * ISO 8601 UTC timestamp for x-captured-at, if NTP has synced.
 * Returns false (and leaves out) if the clock isn't trustworthy yet — the
 * server defaults captured_at to its own receipt time in that case, which is
 * honest: an unsynced device should not assert a capture time it can't back.
 */
bool getIsoTimestamp(char *out, size_t outLen) {
  time_t now;
  time(&now);
  if (now < 1700000000) {  // before ~Nov 2023 means NTP hasn't synced
    return false;
  }
  struct tm timeinfo;
  gmtime_r(&now, &timeinfo);
  strftime(out, outLen, "%Y-%m-%dT%H:%M:%SZ", &timeinfo);
  return true;
}

/**
 * Encode and upload one frame. Returns true on a 2xx response.
 *
 * Failure handling matches Phase 03's stated principle for the main
 * controller, applied here to the vision node: the network is an
 * enhancement, never a dependency. A failed upload is logged and the loop
 * continues to the next scheduled capture — it never blocks, retries in a
 * tight loop, or halts the device.
 */
bool captureAndUpload(const char *trigger) {
  if (USE_FLASH) { digitalWrite(FLASH_LED_PIN, HIGH); delay(FLASH_MS); }
  camera_fb_t *fb = esp_camera_fb_get();
  if (USE_FLASH) digitalWrite(FLASH_LED_PIN, LOW);

  if (!fb) {
    Serial.println("[CAP] capture FAILED (null frame buffer)");
    return false;
  }

  uint8_t *jpgBuf = NULL;
  size_t   jpgLen = 0;
  bool encOk = frame2jpg(fb, JPEG_QUALITY, &jpgBuf, &jpgLen);
  esp_camera_fb_return(fb);

  if (!encOk) {
    Serial.println("[JPG] encode FAILED");
    return false;
  }

  frameCount++;
  Serial.printf("[JPG] #%lu  %u B  heap %u\n", frameCount, (unsigned)jpgLen, ESP.getFreeHeap());

  if (WiFi.status() != WL_CONNECTED) {
    Serial.println("[NET] not connected — skipping upload, keeping frame count");
    free(jpgBuf);
    return false;
  }

  WiFiClientSecure client;
  client.setInsecure();  // KNOWN GAP — see file header

  HTTPClient http;
  http.begin(client, UPLOAD_URL);
  http.addHeader("Content-Type", "image/jpeg");
  http.addHeader("x-device-token", CAMERA_DEVICE_TOKEN);
  http.addHeader("x-trigger", trigger);

  char isoTs[32];
  if (getIsoTimestamp(isoTs, sizeof(isoTs))) {
    http.addHeader("x-captured-at", isoTs);
  }

  uint32_t t0 = millis();
  int code = http.POST(jpgBuf, jpgLen);
  uint32_t tUp = millis() - t0;

  bool ok = (code >= 200 && code < 300);
  if (ok) {
    uploadOk++;
    Serial.printf("[UP ] OK  %s  status %d  %lu ms  (ok=%lu fail=%lu)\n",
                  trigger, code, tUp, uploadOk, uploadFail);
  } else {
    uploadFail++;
    String body = http.getString();
    Serial.printf("[UP ] FAILED  status %d  %lu ms  body: %s\n", code, tUp, body.c_str());
  }

  http.end();
  free(jpgBuf);
  return ok;
}

/**
 * Ask the server whether a snapshot has been requested.
 *
 * Returns true only on an unambiguous yes. Any failure — no network, bad
 * status, unparseable body — returns false and is treated as "nothing
 * requested". A poll that cannot reach the server must never trigger a
 * capture: the scheduled timelapse is the thing that matters, and a network
 * fault should degrade this device to schedule-only, not make it fire
 * unpredictably.
 *
 * Deliberately not using ArduinoJson: the response is a two-field object and
 * a substring check is enough. Pulling in a JSON parser to read one boolean
 * would add a dependency and a heap allocation to a path that runs every ten
 * seconds forever.
 */
bool snapshotRequested() {
  if (WiFi.status() != WL_CONNECTED) return false;

  WiFiClientSecure client;
  client.setInsecure();  // KNOWN GAP — see file header

  HTTPClient http;
  if (!http.begin(client, PENDING_URL)) return false;
  http.addHeader("x-device-token", CAMERA_DEVICE_TOKEN);

  int code = http.GET();
  bool requested = false;
  if (code == 200) {
    String body = http.getString();
    requested = (body.indexOf("\"requested\":true") >= 0);
  } else if (code > 0) {
    Serial.printf("[PLL] status %d\n", code);
  }
  http.end();
  return requested;
}

void setup() {
  pinMode(FLASH_LED_PIN, OUTPUT);
  digitalWrite(FLASH_LED_PIN, LOW);

  Serial.begin(115200);
  delay(1500);
  Serial.println("\n\n=== SDIGF Phase 06 — CAM upload ===");
  Serial.printf("[SYS] PSRAM: %s\n", psramFound() ? "found" : "NOT FOUND");

  if (!initCamera()) {
    Serial.println("[FATAL] halting.");
    while (true) delay(1000);
  }

  Serial.printf("[NET] joining %s\n", WIFI_SSID);
  WiFi.mode(WIFI_STA);
  WiFi.begin(WIFI_SSID, WIFI_PASS);
  uint32_t t0 = millis();
  while (WiFi.status() != WL_CONNECTED && millis() - t0 < 20000) {
    delay(500); Serial.print(".");
  }
  Serial.println();

  if (WiFi.status() == WL_CONNECTED) {
    Serial.printf("[NET] IP  : %s\n", WiFi.localIP().toString().c_str());
    Serial.printf("[NET] RSSI: %d dBm\n", WiFi.RSSI());

    // NTP for x-captured-at. Failure here is non-fatal — see getIsoTimestamp().
    configTime(0, 0, "pool.ntp.org", "time.nist.gov");
    Serial.print("[NTP] syncing");
    char tsCheck[32];
    uint32_t tNtp = millis();
    while (!getIsoTimestamp(tsCheck, sizeof(tsCheck)) && millis() - tNtp < 10000) {
      delay(300); Serial.print(".");
    }
    Serial.println();
    Serial.printf("[NTP] %s\n", getIsoTimestamp(tsCheck, sizeof(tsCheck)) ? tsCheck : "NOT SYNCED — server will timestamp on receipt");
  } else {
    Serial.println("[NET] FAILED — will retry upload attempts each cycle regardless");
  }

  Serial.printf("[CFG] schedule every %lu ms, poll every %lu ms\n",
                (unsigned long)SCHEDULE_INTERVAL_MS, (unsigned long)POLL_INTERVAL_MS);
  Serial.println("=== setup complete ===\n");
}

/**
 * Poll on a short interval; capture on the long one.
 *
 * millis() arithmetic rather than delay() for the schedule, because a 24-hour
 * delay() would make the device deaf to snapshot requests for a whole day.
 * Unsigned subtraction handles the ~49-day millis() rollover correctly without
 * a special case — do not "fix" this into a comparison against a sum.
 */
void loop() {
  static uint32_t lastSchedule = 0;
  static bool firstFrameDone = false;

  // One frame shortly after boot so a freshly-started device proves itself
  // immediately rather than going dark until the first scheduled capture.
  if (!firstFrameDone) {
    captureAndUpload("schedule");
    lastSchedule = millis();
    firstFrameDone = true;
  }

  if (millis() - lastSchedule >= SCHEDULE_INTERVAL_MS) {
    captureAndUpload("schedule");
    lastSchedule = millis();
  }

  if (snapshotRequested()) {
    Serial.println("[PLL] snapshot requested");
    // The server clears the flag when a 'manual' upload arrives, so a failed
    // upload deliberately leaves the request standing to be retried next poll
    // rather than silently swallowing it.
    captureAndUpload("manual");
  }

  delay(POLL_INTERVAL_MS);
}

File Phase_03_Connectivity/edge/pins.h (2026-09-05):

// SDIGF edge — pin map. Source of truth: Phase_01 wiring doc v1.8, Appendix A.
// Change the wiring doc first, then this file. Never the reverse.
#pragma once

// ---- Relays (active-LOW module, 10k pull-up to 3.3V on every IN) ----
#define PIN_RELAY_PUMP        19   // IN1
#define PIN_RELAY_S_FAN       18   // IN2
#define PIN_RELAY_INT_FAN      5   // IN3 — strapping pin, justified (§9)
#define PIN_RELAY_N_FAN       17   // IN4
#define PIN_RELAY_HUMIDIFIER  16   // IN5
#define PIN_RELAY_LIGHTS       4   // IN6 — LED string
#define PIN_RELAY_GROW_LIGHT  23   // IN7 — 220 V mains. Never on a strapping pin.

// ---- Servo ----
#define PIN_SERVO_CANOPY      25

// ---- E-stop indicator (v1.8) ----
#define PIN_ESTOP_LED          2   // 220 Ω to GND; strapping pin, harmless case (§7.10)

// ---- I²C ----
#define PIN_I2C_SDA           21
#define PIN_I2C_SCL           22

// ---- DHT11 ----
#define PIN_DHT_IN            26
#define PIN_DHT_OUT           27

// ---- ADC1 only (ADC2 is dead while WiFi is on) ----
#define PIN_LDR_IN            36
#define PIN_LDR_OUT           39
#define PIN_SOIL              34
#define PIN_WATER             35
#define PIN_MQ135             32   // via 2.2k/3.3k divider

// ---- Encoder ----
#define PIN_ENC_CLK           13
#define PIN_ENC_DT            14
#define PIN_ENC_SW            33

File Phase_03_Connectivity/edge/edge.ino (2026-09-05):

// SDIGF — edge controller firmware. ESP32-WROOM-32E.
//
// STAGE B: config reception, hash check, freshness, envelope, ack.
// (Stage A: connectivity on bare silicon.) Nothing wired but USB. Proves the
// device speaks contract v4 to the live broker: status with last will,
// up/health, up/telemetry (all readings honestly "init"), up/actuators (all
// off). Subscribes to down/# so stage B can attach handlers.
//
// LAYERS, and why they exist before any control logic does:
//   sensors     — stubbed now, real in Phase 02. Interface will not change.
//   actuators   — real GPIO now. The only file that knows active-LOW.
//   estop       — reads NVS, drives the LED. Trigger/clear come later.
//   mqtt_link   — everything network. Never blocks the loop.
//   CONTROL LOOP — the named empty slot below. Phase 02 fills it.
//
// Phase 03 was started before Phase 02 by decision (6 Sep 2026). The layer
// boundaries are the safeguard: connectivity plugs INTO control, never the
// reverse. If a later change makes the control loop depend on this file's
// network state, that is the design failure to catch in review.
//
// Toolchain: Arduino IDE, esp32 core 3.x. Board: "ESP32 Dev Module".
// Libraries: PubSubClient, ArduinoJson (7.x). mbedTLS and Preferences are in
// the core.

#include <Arduino.h>
#include <WiFi.h>
#include <time.h>
#include "pins.h"
#include "secrets.h"
#include "actuators.h"
#include "sensors.h"
#include "estop.h"
#include "mqtt_link.h"
#include "config_store.h"

// v4 §2: telemetry interval is FIXED at 30 s. Not a tuning knob.
#define TELEMETRY_INTERVAL_MS  (30UL * 1000UL)
#define HEALTH_INTERVAL_MS     (60UL * 1000UL)
#define ACTUATORS_INTERVAL_MS  (60UL * 1000UL)   // retained; also sent on every state change later

static uint32_t tTelemetry = 0, tHealth = 0, tActuators = 0;

void setup() {
  // ORDER IS THE SAFETY ARGUMENT. Wiring doc §9.
  actuatorsSafeInit();   // 1. every relay pin HIGH (off). Before anything.
  estopInit();           // 2. LED reflects the persisted flag. Before Serial.

  Serial.begin(115200);
  delay(300);
  Serial.println("\n\n=== SDIGF edge " FW_VERSION " — stage B ===");
  Serial.printf("[SYS] boot: relays safe, e-stop %s (origin %s%s)\n",
                estopGet().active ? "ACTIVE" : "clear",
                estopGet().origin == ORIGIN_LOCAL ? "local" : "remote",
                estopGet().nvs_valid ? "" : ", NVS absent → fail-closed remote");
  Serial.printf("[SYS] heap %u  min %u\n", ESP.getFreeHeap(), ESP.getMinFreeHeap());

  sensorsInit();
  configStoreInit();
  {
    const AppliedConfig& ac = configApplied();
    Serial.printf("[CFG] applied: ver %lu src %s%s\n", (unsigned long)ac.ver, CFG_SRC_STR[ac.src],
                  ac.src == CFG_SRC_NVS ? " (last-known-good restored from NVS)" : "");
  }
  mqttInit();

  Serial.printf("[NET] joining %s\n", WIFI_SSID);
  WiFi.mode(WIFI_STA);
  WiFi.begin(WIFI_SSID, WIFI_PASS);
  uint32_t t0 = millis();
  while (WiFi.status() != WL_CONNECTED && millis() - t0 < 20000) { delay(250); Serial.print("."); }
  Serial.println();
  if (WiFi.status() == WL_CONNECTED) {
    Serial.printf("[NET] IP %s  RSSI %d dBm\n", WiFi.localIP().toString().c_str(), WiFi.RSSI());
    configTime(0, 0, "pool.ntp.org", "time.nist.gov");
  } else {
    Serial.println("[NET] not connected — control would continue regardless; retrying in loop");
  }
  Serial.println("=== setup complete ===\n");
}

void loop() {
  // Network first so inbound messages are pumped, but it never blocks.
  if (WiFi.status() != WL_CONNECTED) WiFi.reconnect();
  mqttLoop();

  sensorsPoll();

  // ┌─────────────────────────────────────────────────────────────────┐
  // │ CONTROL LOOP — Phase 02.                                        │
  // │ Threshold+hysteresis per variable, rule arbiter, safety         │
  // │ envelope, overrides, e-stop enforcement. Reads sensorGet(),     │
  // │ writes actuatorSet(). Must not read anything from mqtt_link.    │
  // └─────────────────────────────────────────────────────────────────┘

  uint32_t now = millis();
  if (mqttConnected()) {
    if (now - tTelemetry >= TELEMETRY_INTERVAL_MS) { tTelemetry = now; publishTelemetry(); }
    if (now - tHealth    >= HEALTH_INTERVAL_MS)    { tHealth    = now; publishHealth(); }
    if (now - tActuators >= ACTUATORS_INTERVAL_MS) { tActuators = now; publishActuators(); }
  }
  delay(10);
}

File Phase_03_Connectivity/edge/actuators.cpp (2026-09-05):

#include <Arduino.h>
#include "actuators.h"
#include "pins.h"

const char* const ACTUATOR_KEYS[ACT_COUNT] = {
  "pump", "s_fan", "internal_fan", "n_fan", "humidifier", "lights", "grow_light"
};

static const uint8_t PINS[ACT_COUNT] = {
  PIN_RELAY_PUMP, PIN_RELAY_S_FAN, PIN_RELAY_INT_FAN, PIN_RELAY_N_FAN,
  PIN_RELAY_HUMIDIFIER, PIN_RELAY_LIGHTS, PIN_RELAY_GROW_LIGHT
};

static ActuatorState state[ACT_COUNT];

// Active-LOW: logical ON = electrical LOW. This is the one place that fact lives.
static inline void drive(uint8_t pin, bool on) {
  digitalWrite(pin, on ? LOW : HIGH);
}

void actuatorsSafeInit() {
  for (uint8_t i = 0; i < ACT_COUNT; i++) {
    // Write HIGH before switching to OUTPUT so the pin never drives LOW,
    // not even for the microseconds between the two calls.
    digitalWrite(PINS[i], HIGH);
    pinMode(PINS[i], OUTPUT);
    digitalWrite(PINS[i], HIGH);
    state[i] = { false, SRC_AUTO, (uint32_t)millis(), 0 };
  }
}

void actuatorSet(ActuatorId id, bool on, ActuatorSrc src) {
  if (id >= ACT_COUNT) return;
  ActuatorState& s = state[id];
  if (s.on != on) s.since_ms = millis();
  s.on  = on;
  s.src = src;
  drive(PINS[id], on);
}

const ActuatorState& actuatorGet(ActuatorId id) {
  return state[id < ACT_COUNT ? id : 0];
}

uint8_t actuatorVentStage() {
  return (uint8_t)(state[ACT_S_FAN].on + state[ACT_INT_FAN].on + state[ACT_N_FAN].on);
}

void actuatorsAllOff() {
  for (uint8_t i = 0; i < ACT_COUNT; i++) actuatorSet((ActuatorId)i, false, SRC_SAFETY);
}

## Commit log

2026-06-19 Phase 1 v 1.0
2026-06-19 Visualized Project Prototype
2026-08-23 Final Hardware Documenting - Without Circuit Drawed
2026-08-23 Phase 00 - Added
    [Addition.stl, P1 x4.stl, P2 x4.stl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]
2026-08-24 file path changes
    [Addition.stl, P1 x4.stl, P2 x4.stl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]
2026-08-24 Contracts Documenting Added -Strictly to Topic Tree, QoS/Retain -Payload Schemas -Config Structure -Canonical Hash Spec (Simplified - no hash check from ESP32 - Only ack the hash to the server where 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
2026-08-25 Phase 05a: dashboard shell, status strip, live sensor panels
2026-08-25 Phase 05a: actuators page with overrides and manual commands
2026-08-25 Phase 05a: activity feed and camera placeholder — all five routes complete
2026-08-26 Phase 05a: sensor history charts with honest gaps and scaling
2026-08-26 Phase 04c: -Mock Validates -Mock Applies -Mock Acknowledges Config & Commands -Mock in this phase simulates the ESP32
2026-08-26 Phase 05b: -Wire auth into routes -Every Mutation is Gated by the Role Matrix
2026-08-27 EDITS: -Contract V4 Updated -Emergency Stop Handlers Added -Backend Reshape -Mock Simulator (Updated to fit Emergency Case) -DB Migration 004 Added
2026-08-31 Phase 07: ledger schema - explicit seq, no FKs, stored canonical
2026-08-31 Phase 07: pure link core - frozen wire names and time expression
2026-08-31 Phase 07: ledger service - append, backfill, verifyChain
2026-08-31 Phase 07: ledger tests - frozen time vectors, wire names, INT8 pin
2026-08-31 Phase 07: warn that the ledger's hashes depend on the INT8 type parser
2026-08-31 Phase 07: e-stop ledger append - best-effort, awaited after publish, never throws
2026-09-01 Phase 07: ledger verify endpoint and Activity panel - result, boundary and scope
2026-09-01 Phase 07: fix ledger panel - api.js returns an envelope and never throws
2026-09-03 05c: -Migration 007, provider_settings underenvelope encryption; PROVIDER_CONFIG_CHANGED event type -Provider-crypto; AES-256-GCM seal/open, KEK parsing, rotation-vs-tamper fingerprint -Provider-cryp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
2026-09-03 05c: mcp/tools — eight read-only tools in MCP tools/list + tools/call shape; flags and staleness shaped into text before the model sees it
2026-09-03 05c: -mcp/brief - system brief as approved, role framing as context, not capability filter
2026-09-03 05c: mcp/guard — post-generation checks for ledger overclaim, stale-as-current, self-regulating, growing values, secrets; bounded rejection loop
2026-09-03 05c: guard tests (25, database-free) — including the false-positive cases that must pass
2026-09-03 05c: migration 008 + PROVIDERS — OpenAI accepted alongside Anthropic
2026-09-03 05c: chat-service — status-first turn loop, session-forwarded tools, Anthropic and OpenAI adapters, guarded generation
2026-09-03 05c: routes — GET/POST /api/provider (admin, write-only key), GET /api/chat/status, POST /api/chat (session-forwarded)
2026-09-03 05c: compose — pass PROVIDER_KEK from Dokploy environment into the backend container
2026-09-03 05c: migration 009 — provider_settings.updated_by TEXT to match users.id (007 assumed UUID)
2026-09-03 05c: admin UI — write-only provider key panel; api client gains provider and chat calls
2026-09-03 05c: chat UI — Assistant page with per-turn freshness and guard verdict at full weight; rolenote.danger
2026-09-03 Phase 06: CAM bring-up sketch — camera, PSRAM, WiFi verified on hardware
2026-09-03 Phase 06: -Software JPEG encoding - nearly ~7.2KB/Frame at 21x -100ms, Heap stable
2026-09-03 Phase 06: camera_images and camera_pending tables
2026-09-03 Phase 06: camera image storage service
2026-09-03 Phase 06: device bearer-token auth, separate from user sessions
2026-09-03 Phase 06: camera routes — upload, pending, latest, image, request-snapshot
2026-09-03 Phase 06: export errorResponse, map CameraError codes
2026-09-03 Phase 06: camera env config
2026-09-03 Phase 06: register camera routes
2026-09-03 Phase 06: camera image volume and device token env vars
2026-09-03 Phase 06: create and chown camera image dir before dropping to USER node
2026-09-04 Phase 06: device upload to server - 201 confirmed, NTP timestamps, brownout on second upload under investigation
    [cam_bringup.ino]
2026-09-04 Phase 06: camera API client methods
2026-09-04 Phase 06: Camera page live - latest image, metadata, snapshot request
2026-09-04 Phase 06: listByDay - camera history grouped by UTC day
2026-09-05 Documenting Phase 06: phase record - sensor mismatch, two hardware faults, open items
2026-09-05 Emergency Button Added: -Documentation Edited
2026-09-05 Phase 03 stage B: applied-config store in NVS, cfg.src none|nvs|mqtt
2026-09-05 Phase 03 stage B: safety envelope, ported from mock safety.js
2026-09-05 Phase 03 stage B: down/config handler - parse, schema, SHA-256, freshness, envelope, apply
2026-09-05 Phase 03 stage B: route down/config, publish up/ack, verify declared unsupported
